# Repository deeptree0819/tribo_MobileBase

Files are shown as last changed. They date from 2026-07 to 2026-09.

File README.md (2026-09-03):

# Tribo MobileBase

Yahboom **Rosmaster STM32 ROS 확장보드** 기반 차동구동(differential drive) 모바일 로봇용 ROS 2 패키지.
새 로봇(Ubuntu 24.04 / ROS 2 Jazzy)에서 처음부터 세팅하는 절차를 정리한 문서입니다.

> 기존 환경은 **ROS 2 Jazzy + Ubuntu 24.04** 기준입니다. 다른 배포판을 쓴다면 아래 `jazzy`를 해당 배포판 이름으로 바꾸세요.

---

## 1. 패키지 구성

| 패키지 | 역할 |
|---|---|
| `tribo_bringup` | HW 인터페이스: `/cmd_vel` → 모터 PWM, 엔코더 퍼블리시 (`tribolib.py` 사용) |
| `tribo_odom` | 엔코더 → `/odom` + TF (`odom`→`base_link`) |
| `tribo_description` | URDF(xacro) 로봇 모델 |
| `tribo_navigation`  | Nav2 / SLAM Toolbox 설정·런치 |
| `tribo_gazebo` | Gazebo 시뮬레이션 |
| `sllidar_ros2` | RPLIDAR 드라이버 (**git 서브모듈**) |
| `hardware` | Tribo mobile base의 설계 파일 |

데이터 흐름: `bringup`(보드 시리얼) → `encoder_raw` → `odom_publisher`(`/odom`+TF) → `nav2`

---

## 2. 사전 요구사항

- Ubuntu 24.04
- [ROS 2 Jazzy](https://docs.ros.org/en/jazzy/Installation.html) 설치 완료
- Yahboom Rosmaster STM32 확장보드 (USB-시리얼 CH340) 연결
- RPLIDAR (C1 등, USB-시리얼 CP2102N) 연결

---

## 3. 원격 접속 (SSH) 설정 — 헤드리스 라즈베리파이

라즈베리파이 기반 로봇은 보통 모니터 없이 PC에서 SSH로 접속해 작업합니다. **새로 설치한 OS는 SSH 서버(sshd)가 없거나 비활성 상태**일 수 있어, 처음 한 번은 직접 켜줘야 합니다.

### 3-1. 증상 진단 (PC에서)

PC에서 접속이 안 될 때, 먼저 원인을 구분합니다.

```bash
ping -c 3 <robot-ip>           # 호스트가 살아있는지
nc -vz <robot-ip> 22           # 22번 포트(sshd) 상태
```

| `nc` 결과 | 의미 | 조치 |
|---|---|---|
| `succeeded` | sshd 정상 | 바로 `ssh` 접속 (3-3) |
| `Connection refused` | 호스트는 살아있으나 **sshd 미기동/미설치** | 3-2로 |
| `timed out` | 방화벽 차단 또는 IP/네트워크 문제 | IP 재확인 / `sudo ufw allow ssh` |

> `ping`은 되는데 `nc ... 22`가 **Connection refused**면 거의 항상 라즈베리파이의 SSH가 꺼져 있는 것입니다(네트워크·IP는 정상).

### 3-2. SSH 서버 설치·활성화 (라즈베리파이 본체에서)

모니터+키보드를 연결하거나 SD카드 콘솔에서 실행합니다.

```bash
# 이미 설치돼 있고 꺼져만 있다면 이 줄만으로 충분
sudo systemctl enable --now ssh

# "Unit ssh.service not found"처럼 sshd 자체가 없다면 설치부터
sudo apt update
sudo apt install -y openssh-server
sudo systemctl enable --now ssh

sudo systemctl status ssh      # active (running) 확인
```

> 헤드리스(모니터 없음)로 처음부터 켜려면: SD카드를 PC에 꽂아 boot 파티션에 **빈 `ssh` 파일**(확장자 없음)을 만들면 부팅 시 자동 활성화됩니다 — `touch /media/$USER/bootfs/ssh` (파티션명은 `ls /media/$USER/`로 확인).

### 3-3. 접속 확인 (PC에서)

```bash
nc -vz <robot-ip> 22           # 이제 succeeded!
ssh <robot-user>@<robot-ip>    # 예: ssh tribo@192.168.210.20
```

> 로봇마다 **계정명이 다를 수 있습니다.** 라즈베리파이에서 `whoami`로 확인하세요. `tribo` 같은 접속 alias를 쓴다면 `type tribo`로 실제 가리키는 대상이 해당 로봇과 맞는지 점검하세요(IP만 바꾸고 옛 계정을 가리키면 인증 단계에서 실패).
>
> 여기까지는 IP로 접속하지만, 키 등록(3-4) 후에는 **3-4-1처럼 호스트명 별칭(`tribo-robot`)으로 고정**하는 것을 권장합니다. 이 문서의 이후 예시는 모두 그 별칭을 씁니다.

### 3-4. SSH 키 등록 (비밀번호 없이 접속)

매번 비밀번호를 입력하지 않도록 PC의 공개키를 로봇에 등록합니다. 자동화 스크립트나 `scp`, 원격 launch에도 필수입니다.

```bash
# PC에 키가 없다면 먼저 생성 (이미 있으면 생략)
ls ~/.ssh/id_ed25519.pub || ssh-keygen -t ed25519

# 공개키를 로봇에 등록 — 이때 한 번만 비밀번호 입력
ssh-copy-id <robot-user>@<robot-ip>      # 예: ssh-copy-id tribo@192.168.210.20

# 확인 — 이제 비밀번호 없이 접속돼야 함
ssh <robot-user>@<robot-ip> 'echo OK'
```

### 3-4-1. 로봇 IP 확인하고 접속하기

**tribo 기체는 모두 같은 이미지로 굽기 때문에 hostname이 전부 `tribo-robot`으로 동일합니다.** 그래서 `tribo-robot.local` 같은 mDNS 이름으로는 **어느 기체인지 특정할 수 없습니다.** 같은 와이파이에 두 대 이상 켜면 이름이 충돌해, 접속이 실패하는 게 아니라 **"먼저 부팅한 아무 기체"에 붙습니다** — 의도한 로봇이 아닐 수 있는데도 성공한 것처럼 보이므로 가장 위험한 실패 방식입니다.

따라서 **접속 대상 로봇에서 직접 IP를 확인한 뒤 그 IP로 붙습니다.**

```bash
# ① 로봇에서 (모니터·키보드 연결 상태) — 자기 IP 확인
hostname -I                    # 가장 간단. 예: 192.168.210.23
ifconfig wlan0 | grep inet     # 또는 이렇게
```

```bash
# ② PC에서 — 확인한 IP로 접속
ssh tribo@192.168.210.23
```

> **IP는 DHCP라 재부팅 때마다 바뀔 수 있습니다.** 접속이 안 되면 ①부터 다시 하세요. 특히 **옛 IP를 다른 기기가 가져간 경우 `timed out`이 아니라 `Connection refused`가 뜹니다** — "로봇이 꺼졌다"고 오진하기 쉬우니, 증상보다 ①의 실제 IP를 믿으세요.

**IP를 여러 곳에 흩뿌리지 마세요.** 확인한 IP는 `~/.ssh/config` **한 곳에만** 적고, 나머지 명령·스크립트·문서는 별칭(`tribo-robot`)만 참조합니다. IP가 바뀌면 이 파일의 `HostName` 한 줄만 고치면 됩니다.

```bash
# PC ~/.ssh/config — IP를 적는 유일한 장소
Host tribo-robot
  HostName 192.168.210.23        # ← ①에서 확인한 IP. 바뀌면 이 줄만 갱신
  User tribo
  IdentityFile ~/.ssh/id_ed25519
  StrictHostKeyChecking accept-new
```

```bash
ssh tribo-robot 'hostname'       # → tribo-robot (접속 확인)
```

#### 지금 붙은 게 정말 그 기체인가 — 시리얼로 확인

hostname이 전부 같으므로 이름으로는 기체를 구별할 수 없습니다. **라즈베리파이 시리얼은 SoC에 박혀 있어 위조·변경이 불가능하므로**, 여러 대를 다룰 때는 이것을 기체 식별의 기준으로 삼으세요.

```bash
ssh tribo-robot 'grep -m1 "^Serial" /proc/cpuinfo'
# Serial : 7b6a4fe0834ff68f    ← 이 기체의 고유 번호
```

기체별 시리얼을 적어두고, 캘리브·배포 전에 대조하면 **엉뚱한 로봇에 밀어 넣는 사고를 막을 수 있습니다.**

| 기체 | Pi 시리얼 | 비고 |
|---|---|---|
| v2 | `7b6a4fe0834ff68f` | Raspberry Pi 5 Model B Rev 1.1 |
| v1 | (미확인) | 켤 때 채워 넣을 것 |
| v3 | (미확인) | 켤 때 채워 넣을 것 |

> **기체를 교체하면** hostname·IP가 같아도 SSH 호스트키가 다르므로 `REMOTE HOST IDENTIFICATION HAS CHANGED` 경고가 뜹니다. 기체를 바꾼 게 맞다면 정상이니 3-5의 절차로 옛 키를 지우고 재접속하세요. **다만 기체를 바꾼 적이 없는데 이 경고가 뜬다면 지우지 말고 의심하세요** — 의도치 않게 다른 로봇에 붙고 있다는 신호입니다.

### 3-4-2. 자주 쓰는 alias 모음 (선택)

작업 편의를 위해 `~/.bashrc`에 아래를 둘 수 있습니다. 실제로 쓰고 있는 구성입니다.

```bash
# PC + 로봇 공통 — 워크스페이스 활성화
alias tribo_ws="source ~/tribo_ws/install/local_setup.bash; echo \"tribo_ws is activated\""

# PC — 로봇 접속 (IP는 ~/.ssh/config 의 tribo-robot 한 곳에서만 관리)
alias tribo="ssh tribo-robot"       # 접속은 이걸로: $ tribo

# PC — 실행 중인 launch 정리 (Ctrl+C로 안 죽은 노드가 남을 때)
alias kbringup='pkill -f "ros2 launch tribo_bringup"'
alias knav='pkill -f "ros2 launch tribo_navigation"'
alias kall='pkill -f "ros2 launch tribo"'      # bringup + navigation 전부
```

수정 후 `source ~/.bashrc` 로 반영합니다.

> **이름이 둘인 이유** — 헷갈리기 쉬우니 정리하면:
> - **`tribo`** = PC에서 **사람이 직접 치는** 접속 alias. 터미널에서 `tribo` 한 단어면 로봇에 붙습니다.
> - **`tribo-robot`** = `~/.ssh/config` 의 **Host 별칭**. bash alias는 대화형 셸에서만 로드되므로 `scp`·스크립트·`ssh <host> '<command>'` 같은 비대화형 호출에는 안 먹습니다. 그런 곳에는 `tribo-robot` 을 쓰세요 (예: `scp map.yaml tribo-robot:~/`).
>
> 즉 **PC에서 접속할 땐 `tribo`, 문서·스크립트에 적을 땐 `tribo-robot`** 입니다. **IP는 `~/.ssh/config` 에만 적고, 이 둘 어디에도 쓰지 않습니다** — 그래야 IP가 바뀌어도 고칠 곳이 한 줄뿐입니다.

### 3-5. 호스트키 변경 경고 — 같은 이름/IP로 다른 로봇에 접속할 때 (PC에서)

**기체를 바꿨거나**(tribo v1 → v2 처럼 hostname이 같은 다른 장비), 기존 로봇과 **같은 IP를 재사용하는 새 로봇**(재설치/보드 교체 포함)에 접속하면, 그 장비는 다른 호스트키를 갖고 있어 PC가 이렇게 막습니다.

```
@@@@@@@@@@@@@@@@@@@@@@@@@@@@@@@@@@@@@@@@@@@@@@@@@@@@@@@@@@@
@    WARNING: REMOTE HOST IDENTIFICATION HAS CHANGED!     @
@@@@@@@@@@@@@@@@@@@@@@@@@@@@@@@@@@@@@@@@@@@@@@@@@@@@@@@@@@@
...
Offending ED25519 key in /home/<user>/.ssh/known_hosts:41
Host key verification failed.
```

이건 MITM 공격이 아니라 **로봇이 바뀌었으니 당연한 경고**입니다(PC의 `known_hosts`에 옛 로봇의 키가 남아 있는 것). 해당 IP의 옛 키만 지우면 됩니다.

```bash
# PC에서 — 옛 호스트키 제거 (백업은 known_hosts.old 로 자동 보관됨)
ssh-keygen -f ~/.ssh/known_hosts -R <robot-ip>      # 예: -R 192.168.210.23

# 다시 접속하면 새 키 등록 여부를 물어봄 → yes
ssh <robot-user>@<robot-ip>
# The authenticity of host ... can't be established.
# Are you sure you want to continue connecting (yes/no/[fingerprint])?  → yes
```

> 접속이 뜨면 로봇에서 `whoami`/`hostname`으로 **계정·호스트명이 맞는 로봇인지** 한 번 확인하세요(옛 로봇과 IP만 같고 실제로 다른 장비일 수 있음). 이후 `ssh-copy-id`(3-4)로 공개키를 다시 등록하면 비밀번호 없이 접속됩니다.

---

## 4. 설치

> **📍 대상: PC와 로봇 양쪽에서 각각 수행합니다.** 두 머신 모두 자기 `~/tribo_ws`를 갖고 빌드합니다 — 로봇은 실제 bringup·주행용, PC는 시뮬레이션·RViz·개발용. (하드웨어 설정인 5장만 **로봇 전용**입니다.)
>
> | 소절 | PC | 로봇 | 비고 |
> |------|:--:|:----:|------|
> | 4-1 시스템 의존성 | ✅ | ✅ | `python3-serial`은 실제로는 로봇에서만 쓰이나, 설치해 둬도 무해 |
> | 4-2 ROS 2 패키지 의존성 | ✅ | ✅ | 시뮬(gazebo) 블록은 **PC만** |
> | 4-3 워크스페이스 clone | ✅ | ✅ | 각 머신에 독립적으로 clone |
> | 4-4 빌드 | ✅ | ✅ | 각 머신에서 `colcon build` |

### 4-1. 시스템 의존성 &nbsp;·&nbsp; 🖥️ PC + 🤖 로봇

```bash
sudo apt update
sudo apt install -y \
  python3-serial \
  python3-colcon-common-extensions \
  git
```

> `python3-serial`(pyserial)은 `tribolib.py`가 보드와 통신하는 데 **유일하게 필요한 외부 파이썬 의존성**입니다. (Yahboom의 `Rosmaster_Lib`는 따로 설치할 필요 없음 — `tribolib.py`가 프로토콜을 자체 구현)
>
> `python3-colcon-common-extensions`가 `Unable to locate package`로 안 잡히면 **ROS 2 apt 저장소가 아직 추가되지 않은 것**입니다(이 패키지는 packages.ros.org에 있음). 2장의 ROS 2 Jazzy 설치를 먼저 끝내면 잡힙니다.

### 4-2. ROS 2 패키지 의존성 &nbsp;·&nbsp; 🖥️ PC + 🤖 로봇

```bash
sudo apt install -y \
  ros-jazzy-geometry-msgs \
  ros-jazzy-sensor-msgs \
  ros-jazzy-std-msgs \
  ros-jazzy-nav-msgs \
  ros-jazzy-tf2-ros \
  ros-jazzy-xacro \
  ros-jazzy-joint-state-publisher \
  ros-jazzy-joint-state-publisher-gui \
  ros-jazzy-robot-state-publisher \
  ros-jazzy-rviz2 \
  ros-jazzy-nav2-bringup \
  ros-jazzy-slam-toolbox \
  ros-jazzy-laser-filters
```

> `laser_filters`는 라이다 자기 몸체(기둥·버튼 등) 반사를 걸러 `/scan` → `/scan_filtered`를 만듭니다. **필수입니다.** 빠지면 map_building이 `package 'laser_filters' not found`로 즉시 죽습니다.
>
> ⚠️ `use_scan_filter:=false`는 **우회 수단이 아닙니다.** 필터 노드만 안 띄울 뿐, SLAM·AMCL·nav2 코스트맵은 전부 `/scan_filtered`를 구독하도록 설정돼 있어(`nav2_params.yaml`, `slam_toolbox_mapping.yaml`, `nav2_localization.yaml`) 아무도 발행하지 않는 토픽을 기다리며 스캔을 한 개도 못 받습니다. 런치는 뜨지만 맵이 안 그려집니다.

시뮬레이션(`tribo_gazebo`)도 쓸 경우 &nbsp;·&nbsp; **🖥️ PC 전용** (로봇에선 불필요):

```bash
sudo apt install -y \
  ros-jazzy-ros-gz-sim \
  ros-jazzy-ros-gz-bridge \
  ros-jazzy-ros-gz-image
```

### 4-3. 워크스페이스 클론 (서브모듈 포함) &nbsp;·&nbsp; 🖥️ PC + 🤖 로봇 (각각)

`sllidar_ros2`는 서브모듈이므로 `--recurse-submodules`가 필수입니다.

```bash
mkdir -p ~/tribo_ws/src
cd ~/tribo_ws/src
git clone --recurse-submodules https://github.com/deeptree0819/tribo_MobileBase.git tribo

# 이미 서브모듈 없이 클론했다면:
cd ~/tribo_ws/src/tribo
git submodule update --init --recursive
```

### 4-4. 빌드 &nbsp;·&nbsp; 🖥️ PC + 🤖 로봇 (각각)

```bash
cd ~/tribo_ws
source /opt/ros/jazzy/setup.bash
colcon build --symlink-install
source install/setup.bash
```

---

## 5. 하드웨어 설정 &nbsp;·&nbsp; 🤖 로봇 전용

### 5-1. 시리얼 포트 접근 권한

`dialout` 그룹에 사용자를 추가해야 보드/라이다 시리얼 포트(`/dev/ttyUSB*`)에 접근할 수 있습니다. 추가하지 않으면 bringup이 `could not open port` 로 실패합니다.

```bash
# 로봇에서 (SSH로 접속한 상태). sudo 비밀번호를 한 번 입력
sudo usermod -aG dialout $USER

# 그룹 변경은 새 로그인 세션부터 적용 → 재로그인(또는 재부팅) 필수
exit
ssh <robot-user>@<robot-ip>     # 다시 접속
# 또는: sudo reboot

# 확인 — 목록에 dialout 이 보이면 성공
groups
# tribo adm dialout cdrom sudo ...
```

> `/dev/ttyUSB0` 권한은 `crw-rw---- root dialout`이라, dialout 그룹에 들기 전에는 같은 사용자라도 포트를 열 수 없습니다.

CH340 / CP2102 드라이버는 최신 커널에 기본 내장돼 있어 보통 별도 설치가 필요 없습니다.
연결 확인:

```bash
ls -l /dev/serial/by-id/
# 예시:
#   usb-1a86_USB_Serial-if00-port0                → 보드(ttyUSB0)
#   usb-Silicon_Labs_CP2102N_..._if00-port0       → 라이다(ttyUSB1)
```

### 5-2. USB 장치 고정 이름 (udev) — 권장

USB 포트를 다른 소켓에 꽂거나 부팅 순서가 바뀌면 `/dev/ttyUSB0`↔`ttyUSB1`이 뒤바뀌어 **보드와 라이다가 서로 포트를 뺏는** 문제(보드 `multiple access on port`, 라이다 `OPERATION_TIMEOUT`)가 생길 수 있습니다. udev 규칙으로 칩 종류(VID:PID) 기반 고정 심볼릭을 만들어 원천 차단합니다.

repo에 규칙 파일이 포함돼 있습니다: `tribo_bringup/udev/99-tribo-serial.rules`

```bash
# 로봇에서 (sudo 비밀번호 1회)
sudo cp ~/tribo_ws/src/tribo/tribo_bringup/udev/99-tribo-serial.rules /etc/udev/rules.d/
sudo udevadm control --reload-rules && sudo udevadm trigger

# 확인 — 두 심볼릭이 보이면 성공
ls -l /dev/tribo_base /dev/tribo_lidar
#  /dev/tribo_base  -> ../../ttyUSB0
#  /dev/tribo_lidar -> ../../ttyUSB1
```

| 장치 | 매칭 기준 | 고정 이름 |
|---|---|---|
| 보드 (CH340) | VID:PID `1a86:7523` | `/dev/tribo_base`  |
| 라이다 (CP2102N) | VID:PID `10c4:ea60` | `/dev/tribo_lidar` |

> - 보드/라이다 칩이 위와 다르면 규칙 파일의 VID:PID를 자기 장치 값(`udevadm info -q property -n /dev/ttyUSB0`의 `ID_VENDOR_ID`/`ID_MODEL_ID`)으로 바꾸세요.
> - 같은 칩(예: CP2102N 2개)을 동시에 꽂는 경우에만 VID:PID로 구분이 안 됩니다. 그땐 규칙 파일 주석대로 라이다 줄에 `ATTRS{serial}=="<고유시리얼>"`을 추가하세요.

### 5-3. 보드·라이다 포트 해석 (자동)

`bringup.launch.py`가 시작할 때 포트를 **자동 해석**합니다 — udev 심볼릭(`/dev/tribo_base`, `/dev/tribo_lidar`)이 있으면 그것을, 없으면 `/dev/serial/by-id/` 경로로 폴백합니다. 따라서 **5-2의 udev 설치를 건너뛰어도** by-id로 동작하고, ttyUSB 번호 변동에는 항상 안전합니다.

- **보드**: `bringup.yaml`에는 `port`를 두지 않고 launch가 해석한 값을 사용합니다.
- **라이다**: `bringup.launch.py`가 해석한 `serial_port`를 sllidar 런치에 넘깁니다 — `sllidar_c1_launch.py`를 직접 고칠 필요가 없습니다.

> 칩이 다른 보드/라이다를 쓰면 `bringup.launch.py` 상단의 `_resolve_port(...)` 매칭 문자열과 `udev/99-tribo-serial.rules`의 VID:PID를 함께 바꾸세요.

### 5-4. CPU 거버너 = performance ⚠️ (Pi5 + Nav2 필수)

라즈베리파이 기본 CPU 거버너는 `ondemand`라 부하에 따라 클럭을 **천천히** 올립니다. Nav2 12개 노드가 한꺼번에 뜨는 **버스트 시작** 때 클럭(2.4GHz)이 못 따라와서:

- `controller_server`가 costmap 로딩에 너무 오래 걸려 → `lifecycle_manager: get_state service is not available! Aborting bringup` 으로 **nav 전체가 abort**

거버너를 `performance`(전 코어 최대 클럭 고정)로 바꾸면 해결됩니다.

```bash
# 즉시 적용 (재부팅 전까지)
echo performance | sudo tee /sys/devices/system/cpu/cpu*/cpufreq/scaling_governor

# 확인 — performance / 2400000(2.4GHz) 나와야 함
cat /sys/devices/system/cpu/cpu0/cpufreq/scaling_governor
cat /sys/devices/system/cpu/cpu*/cpufreq/scaling_cur_freq
```

재부팅해도 유지하려면 repo의 systemd 서비스를 설치:

```bash
sudo cp ~/tribo_ws/src/tribo/tribo_bringup/system/cpu-performance.service /etc/systemd/system/
sudo systemctl daemon-reload
sudo systemctl enable --now cpu-performance.service
systemctl is-enabled cpu-performance.service                 # enabled 면 OK
systemctl is-active  cpu-performance.service                 # active 면 OK

# 재부팅 후 검증 — 4코어 전부 performance 나와야 함
cat /sys/devices/system/cpu/cpu*/cpufreq/scaling_governor
```

> performance 거버너는 발열·소비전력이 늘어납니다. Pi5는 액티브 쿨러가 있으면 문제없습니다. Nav2를 안 쓰고 bringup만 돌릴 땐 `ondemand`로도 충분합니다.

### 5-5. 뎁스 카메라 (Intel RealSense D435)

#### 5-5-1. USB 3.0 포트에 연결 ⚠️

**가장 흔한 실패 지점입니다.** D435는 depth와 color 영상을 동시에 보내므로 USB 3.0이 필요합니다. USB 2.0에 물리면 동작은 하지만 **프레임레이트가 절반**으로 떨어집니다.

| 연결 | depth | color |
|---|---|---|
| USB 2.0 | 640×480 @ **15 fps** | 640×480 @ **15 fps** |
| USB 3.0 | 848×480 @ **30 fps** | 640×480 @ **30 fps** |

대역폭을 계산하면 이유가 보입니다. depth 640×480×16bit @30fps ≈ 147 Mbps, color도 비슷해서 합치면 약 300 Mbps인데 USB 2.0의 실효 대역폭이 그 언저리입니다. 그래서 librealsense가 두 스트림을 다 내보내려고 **알아서 15fps로 낮춥니다** — 에러가 아니라 조용한 성능 저하라 놓치기 쉽습니다.

- **소켓**: Pi5의 **파란색** USB-A (검은색은 USB 2.0). Pi5의 USB-C는 **전원 전용**이라 데이터가 안 됩니다.
- **케이블**: **USB 3.0 이상, A to C**. USB-A 단자 안쪽이 파란색이고 핀이 9개면 3.0, 흰색이고 4개면 2.0입니다. "고속충전"만 적힌 케이블은 데이터가 2.0인 경우가 흔합니다.

연결 후 협상 속도를 확인합니다. **`5000`이 나와야 정상**이고 `480`이면 USB 2.0입니다.

```bash
for d in /sys/bus/usb/devices/*/; do [ -f "$d/idVendor" ] && [ "$(cat $d/idVendor)" = "8086" ] && cat "$d/speed"; done
```

`480`이 나오면 어느 소켓이 3.0인지 실측으로 찾습니다. 아래를 띄워둔 채 카메라를 뽑았다 꽂으면 소켓마다 한 줄씩 나옵니다 — `SuperSpeed`가 USB 3.0, `high-speed`가 USB 2.0입니다.

```bash
sudo dmesg -w | grep --line-buffered "new .*USB device"
```

> **라이다와 보드는 검은 소켓으로 충분합니다.** 둘 다 USB 시리얼 변환기라 12 Mbps 수준으로 동작합니다. 파란 소켓에 꽂아도 보드레이트(115200~256000 bps)가 상한이라 아무 이득이 없습니다. 파란 소켓 2개는 카메라 몫으로 남겨두세요.

#### 5-5-2. 패키지 설치

ROS 저장소에 arm64 바이너리가 있어 **소스 빌드가 필요 없습니다**.

```bash
sudo apt update
sudo apt install -y ros-jazzy-realsense2-camera ros-jazzy-realsense2-description
```

`ros-jazzy-librealsense2`는 의존성으로 함께 설치됩니다.

> **⚠️ 노드가 `undefined symbol`로 죽으면 `diagnostic_updater`를 올리세요.**
> ROS 패키지를 오래 업데이트하지 않은 기체에서 나타납니다.
>
> ```
> [realsense2_camera_node-1] terminate called after throwing an instance of 'class_loader::LibraryLoadException'
>   what():  Could not load library ... librealsense2_camera.so: undefined symbol: _ZN18diagnostic_updater7Updater...
> ```
>
> 새로 받은 `realsense2_camera`가 빌드된 버전과 기체에 깔린 `diagnostic_updater`의 ABI가 안 맞아서입니다. 해결:
>
> ```bash
> sudo apt install -y --only-upgrade ros-jazzy-diagnostic-updater ros-jazzy-diagnostic-msgs
> ```
>
> (기체 7b6a에서 4.2.6 → 4.2.7 업그레이드로 해결. 같은 날 76c02a는 이미 4.2.7이라 문제가 없었습니다.)

#### 5-5-3. 접근 권한

```bash
sudo usermod -aG video $USER
```

그룹 변경은 **재로그인(또는 재부팅) 후 적용**됩니다.

> **이 단계를 건너뛰면 "될 때도 있고 안 될 때도 있는" 상태가 됩니다.** `/dev/video*`는 `uaccess` 태그가 붙어 있어, 로봇 화면에 사용자가 로그인해 있으면 systemd-logind가 그 세션에 ACL을 임시로 부여합니다. 그래서 LCD에 로그인된 상태에서는 `video` 그룹 없이도 카메라가 열립니다. 하지만 자동 로그인을 끄거나 콘솔 세션이 없으면 SSH로만 접속했을 때 권한 오류가 납니다. `video` 그룹에 넣어두면 세션 상태와 무관하게 항상 열립니다.

#### 5-5-4. 실행

```bash
ros2 launch realsense2_camera rs_launch.py
```

포인트클라우드(`/camera/camera/depth/color/points`)는 기본으로 꺼져 있습니다. 3D로 보려면:

```bash
ros2 launch realsense2_camera rs_launch.py pointcloud.enable:=true
```

#### 5-5-5. 동작 확인

```bash
ros2 topic list | grep camera
ros2 topic hz /camera/camera/depth/image_rect_raw
```

USB 3.0이면 **30 Hz**, USB 2.0이면 15 Hz가 나옵니다. 노드 로그에도 `Device USB type: 3.2`처럼 찍히고, USB 2.0이면 `Reduced performance is expected` 경고가 함께 나옵니다.

| 증상 | 원인 |
|---|---|
| 토픽이 아예 안 보임 | `ROS_DOMAIN_ID` 불일치 (6장 참고) |
| 15 fps에서 안 올라감 | USB 2.0 연결 — 5-5-1 |
| 권한 오류로 열리지 않음 | `video` 그룹 미반영 — 재로그인 필요 |
| 모터가 안 먹음 | 카메라 꽂다가 보드(CH340) USB를 뽑았는지 확인 |

#### 5-5-6. 로봇 LCD에 영상 띄우기

PC 없이 로봇 화면만으로 카메라 영상을 확인할 수 있습니다. 실습·시연에 유용합니다.

**전제 조건 두 가지**가 있습니다.

1. **LCD에 GNOME 세션이 로그인돼 있어야 합니다.** 자동 로그인이 켜져 있으면 부팅만으로 충족됩니다.

```bash
grep AutomaticLogin /etc/gdm3/custom.conf
```

2. **화면이 꺼지지 않아야 합니다.** Ubuntu Desktop 기본값은 5분 뒤 화면을 끄고(`idle-delay=300`), 나아가 **기체 전체를 서스펜드**합니다(`sleep-inactive-ac-type='suspend'`). 로봇에는 둘 다 위험하므로 시스템 기본값으로 꺼둡니다.

```bash
sudo tee /etc/dconf/profile/user <<'EOF'
user-db:user
system-db:local
EOF
sudo mkdir -p /etc/dconf/db/local.d
sudo tee /etc/dconf/db/local.d/00-tribo-lcd <<'EOF'
[org/gnome/desktop/session]
idle-delay=uint32 0

[org/gnome/desktop/screensaver]
lock-enabled=false
idle-activation-enabled=false

[org/gnome/settings-daemon/plugins/power]
idle-dim=false
sleep-inactive-ac-type='nothing'
sleep-inactive-battery-type='nothing'
EOF
sudo dconf update
```

> 사용자 계정 설정(`gsettings set`)이 아니라 **시스템 기본값**으로 두는 이유는, 계정을 새로 만들거나 SD 이미지를 복제해도 그대로 유지되어야 하기 때문입니다. 계정에 개별 설정이 이미 남아 있으면 시스템 기본값이 가려지므로 `dconf reset <키>`로 지워야 합니다.

**띄우기.** 전용 스크립트가 환경변수 조립·전체화면 강제까지 처리합니다.

```bash
sudo apt install -y wmctrl
~/tribo_ws/src/tribo/tribo_bringup/scripts/launch_camera_on_lcd.sh
```

다른 토픽을 보려면 인자로 넘깁니다.

```bash
~/tribo_ws/src/tribo/tribo_bringup/scripts/launch_camera_on_lcd.sh /camera/camera/depth/image_rect_raw
```

`wmctrl`이 없으면 경고를 찍고 창이 작게 뜹니다.

> **depth 를 보려면 `enable_depth:=false` 로 띄우면 안 됩니다.** 그 상태에서도 토픽 이름은 광고되지만 데이터가 흐르지 않아 화면이 검게만 보입니다.
>
> depth 는 컬러 영상이 아니라 **16비트 거리값(`16UC1`, 단위 mm)** 이라 그대로는 표시할 수 없습니다(`[16UC1] is not a color format` 오류). 뷰어가 인코딩을 감지해 자동으로 컬러맵을 입힙니다.
>
> - **파랑 = 가까움, 빨강 = 멀음** (표시 범위 0.3~4.0 m, 스크립트 상단 `DEPTH_MIN_M`/`DEPTH_MAX_M`)
> - **검정 = 측정 실패** — 유리·거울·검은 물체·너무 가까운 면에서 나옵니다. 0 을 그대로 칠하면 "코앞에 물체가 있음"으로 보이므로 일부러 검게 남깁니다
>
> 매 프레임 최소/최대로 정규화하지 않고 **고정 범위**를 쓰는 이유는, 장면이 바뀔 때마다 같은 거리가 다른 색으로 보이면 실습에 쓸 수 없기 때문입니다.

**끄기.** LCD 앞이라면 `q` 또는 `ESC`. SSH라면:

```bash
pkill -f "lcd_camera_view[.]py"
```

카메라 노드까지 내리려면:

```bash
pkill -f realsense2_camera_node
```

> 대괄호(`[.]`)는 오타가 아닙니다. `pkill -f`는 **자기 자신의 명령줄도 검사**하므로, 패턴이 그대로 들어 있으면 스스로를 죽여 뒤 명령이 실행되지 않습니다. `[.]`는 정규식으로는 `.`과 같지만 문자열로는 다르므로 자기 매칭을 피합니다.

**화면이 꺼져 있을 때 깨우기.** 절전 설정을 끄기 **전에** 이미 꺼졌다면 설정만으로는 켜지지 않습니다.

```bash
export DBUS_SESSION_BUS_ADDRESS=unix:path=/run/user/1000/bus
busctl --user call org.gnome.ScreenSaver /org/gnome/ScreenSaver org.gnome.ScreenSaver SetActive b false
```

> 반대로 화면을 **끄는** 것은 같은 호출에 `b true`를 주면 될 것으로 보이지만, 아직 실기에서 확인하지 못했습니다. 확인되면 이 문단을 갱신하세요.

**왜 전용 스크립트인가.** `rqt_image_view`는 창 장식과 툴바가 1024×600 화면의 상당 부분을 먹는데, mutter가 SSH에서 온 리사이즈 요청을 무시해서 크기를 맞출 수도 없습니다(228×169로 뜨는 것을 실측). `lcd_camera_view.py`는 OpenCV 전체화면 창에 영상만 그리고, 화면과 영상의 비율이 달라도 찌그러뜨리지 않고 **비율 유지 확대 후 중앙 크롭**으로 채웁니다.

구현하며 밟은 함정이 스크립트 주석에 남아 있습니다.

| 함정 | 내용 |
|---|---|
| `cv2.getWindowImageRect()` | 창 크기가 아니라 "마지막에 그린 이미지 영역"을 반환. 그 값으로 다시 크기를 정하면 프레임마다 이미지가 줄어듦 |
| `fb0/virtual_size` | 프레임버퍼 콘솔 크기이지 X 모드가 아님. 기체 7b6a에서 fb0는 1024×768, 실제 X는 1024×600. `xrandr`을 써야 함 |
| OpenCV 전체화면 속성 | GNOME Wayland에서 무시됨. `xdotool windowsize`도 무시. `wmctrl -b add,fullscreen`만 먹음 |
| `set -u` + ROS 소싱 | `AMENT_TRACE_SETUP_FILES: unbound variable`로 죽음. 소싱 구간만 `set +u` |

**RViz로 보고 싶다면** (depth·포인트클라우드까지):

```bash
export DISPLAY=:0
export XAUTHORITY=$(ls -t /run/user/$(id -u)/.mutter-Xwaylandauth.* | head -1)
rviz2 --fullscreen
```

좌하단 **Add**로 `Image` 또는 `PointCloud2`를 추가합니다. 포인트클라우드는 카메라를 `pointcloud.enable:=true`로 띄워야 나옵니다.

> Nav2 단계에서는 `bringup_launch.xml`이 `launch_rviz_on_lcd.sh`로 RViz를 자동 표시합니다(7장).

| 증상 | 원인 |
|---|---|
| `cannot open display :0` | LCD에 로그인된 GNOME 세션 없음 — 자동 로그인 확인 |
| `Authorization required` | `XAUTHORITY` 경로가 낡음 — 글롭으로 다시 잡을 것 |
| 창은 떴는데 영상이 검음 | 카메라 노드 미실행 또는 토픽 이름 오타 |
| 창이 작게 뜸 | `wmctrl` 미설치 |
| 화면이 5분 뒤 꺼짐 | 위 dconf 설정 누락 |
| 설정했는데도 화면이 꺼져 있음 | 설정 전에 이미 꺼진 것 — 위 깨우기 명령 실행 |

#### 5-5-7. PC에서 영상 보기

**압축 토픽을 써야 합니다.** 원본을 그대로 구독하면 WiFi가 포화되어 영상뿐 아니라 **Nav2의 costmap·TF 통신까지 밀립니다.**

로봇에 압축 전송 플러그인을 설치하면 `/compressed` 토픽이 생깁니다.

```bash
sudo apt install -y ros-jazzy-compressed-image-transport
```

PC에서:

```bash
export ROS_DOMAIN_ID=38
ros2 run rqt_image_view rqt_image_view /camera/camera/color/image_raw/compressed
```

실측한 대역폭입니다(컬러 1280×720@30, USB 3.0).

| | 메시지 크기 | 30fps 환산 |
|---|---|---|
| 원본 `image_raw` | 2.76 MB | **662 Mbps** |
| 압축 `compressed` | 0.23 MB | **56 Mbps** |

> **압축해도 1280×720@30은 캠퍼스 WiFi에서 버겁습니다.** 실측에서 패킷 손실 33%, RTT 400ms까지 올라가 SSH도 느려졌습니다. Nav2와 함께 쓸 거면 해상도를 낮추세요.
>
> ```bash
> ros2 launch realsense2_camera rs_launch.py enable_depth:=false rgb_camera.profile:=640x480x15
> ```

> **`ROS_DOMAIN_ID`가 다르면 토픽이 아예 안 보입니다.** 기체마다 값이 다릅니다(7b6a=38, 76c02a=21). PC도 같은 값으로 맞추세요.
>
> 로봇 `~/.bashrc`에 넣을 때는 **"비대화형이면 return" 구문보다 위에** 둬야 합니다. 아래에 두면 대화형 셸에서만 잡혀서, `ssh <host> '<명령>'` 형태의 원격 실행에서는 도메인이 0이 되고 "노드가 안 보인다"로 헤매게 됩니다.

---

## 6. ROS_DOMAIN_ID 설정 (PC ↔ 로봇 통신)

PC와 로봇이 서로의 토픽을 보려면 **같은 `ROS_DOMAIN_ID`** 를 써야 합니다. `~/.bashrc` 끝에 추가:

```bash
export ROS_DOMAIN_ID=20          # PC·로봇 동일 값으로
source /opt/ros/jazzy/setup.bash
source ~/tribo_ws/install/setup.bash
```

> alias만 정의해 두고 매번 수동 실행하면 노드별로 도메인이 어긋날 수 있으니, 위처럼 **export로 고정**하는 것을 권장합니다.

---

## 7. 실행

### 7-1. 실제 로봇 bringup (보드 + 오도메트리 + 라이다)

```bash
ros2 launch tribo_bringup bringup.launch.py
```

주요 런치 인자(기본값): `use_odom:=true`, `use_lidar:=true`, `use_description:=true`

모터 구동만 (라이다·odom 제외):

```bash
ros2 launch tribo_bringup bringup.launch.py use_lidar:=false use_odom:=false
```

bringup + odom만 묶은 코어 런치:

```bash
ros2 launch tribo_bringup core.launch.py
```

### 7-2. 동작 테스트

```bash
# 전진 명령 (안전을 위해 바퀴를 들고 테스트 권장)
ros2 topic pub --once /cmd_vel geometry_msgs/Twist "{linear: {x: 0.1}}"
```

> bringup에는 **watchdog**이 있어 `cmd_vel`이 `cmd_timeout`(기본 0.5초)초 동안 끊기면 모터를 자동 정지합니다.

### 7-3. 맵 만들기 (SLAM)

SLAM Toolbox로 지도를 작성합니다. (`ros-jazzy-slam-toolbox` 패키지 필요 — 4-2의 의존성 목록에 포함)

**① 로봇에서: bringup 실행** (모터·오도메트리·라이다·URDF 전체)

```bash
# 로봇 (ssh tribo-robot)
ros2 launch tribo_bringup bringup.launch.py
```

**② SLAM 실행** (로봇 또는 PC, 어느 쪽이든 OK — 같은 `ROS_DOMAIN_ID`만 맞으면 됨)

```bash
ros2 launch tribo_navigation map_building.launch.py
```

이 런치는 내부적으로 다음을 띄웁니다:
- `laser_filters/scan_to_scan_filter_chain` (`/scan` → `/scan_filtered`)
- `slam_toolbox` online sync (`config/slam_toolbox_mapping.yaml`)

**③ 맵이 그려지는 과정 보기**

**로봇 LCD에는 자동으로 뜹니다.** `map_building.launch.py`가 전용 맵 뷰어를 함께 띄웁니다. 맵이 자라면 **배율이 매 프레임 자동으로 맞춰지므로** 실행 중 손댈 것이 없습니다.

| 색 | 의미 |
|---|---|
| 흰색 | 빈 공간 |
| 검정 | 장애물 |
| 회색 | 미탐색 |
| 빨강 점 | 로봇 현재 위치 |

좌하단에 현재 표시 범위가 미터로 찍힙니다. 맵이 커지면 이 숫자가 커집니다.

```bash
# 끄려면
ros2 launch tribo_navigation map_building.launch.py use_lcd_map:=false

# 맵 뷰어 대신 RViz 를 LCD 에 띄우려면 (라이다 스캔·TF 까지 보고 싶을 때)
ros2 launch tribo_navigation map_building.launch.py use_rviz:=true use_lcd_map:=false
```

> RViz 를 쓰지 않는 이유: RViz 의 배율은 설정 파일에 박힌 고정값이라 실행 중 바꾸려면 마우스 휠이 필요한데, 로봇에는 마우스도 키보드도 없습니다. 맵은 매핑 중 계속 자라므로 고정 배율로는 곧 화면을 벗어납니다. 둘을 동시에 켜면 같은 화면을 두고 다투니 하나만 쓰세요.

**PC에서도 보려면** 뷰어를 따로 실행합니다.

```bash
# PC — /map, /scan, 로봇 모델을 map_building.rviz 설정으로 표시
ros2 launch tribo_navigation map_view.launch.py
```

- 실시간으로 채워지는 맵을 보며 아직 안 그려진 곳을 향해 로봇을 몰면 됩니다.
- 시뮬(Gazebo)이면 `use_sim_time:=true`를 붙이세요(안 그러면 TF 시간 불일치로 화면이 비거나 깨짐).
- 순수 뷰어라 로봇 노드는 하나도 안 띄웁니다. 끄거나 재시작해도 SLAM에 영향 없습니다.

**④ 텔레옵으로 주행하며 매핑**

```bash
# 별도 터미널에서 (PC 권장)
ros2 run teleop_twist_keyboard teleop_twist_keyboard
```

> 너무 빠르거나 급회전하면 스캔 매칭이 깨집니다. 천천히, 겹치는 구간을 만들면서 한 바퀴 돌리세요.

**⑤ 맵 저장**

`map_saver_cli`는 **실행한 머신의 현재 경로**에 `<이름>.yaml` + `<이름>.pgm` 두 파일을 저장합니다. Nav2가 결국 **로봇에서** map을 로드하므로, 가능하면 **로봇에서 저장**하는 게 가장 간단합니다.

```bash
# 로봇에서 저장 → /home/tribo/my_map.{yaml,pgm} 생성됨
ros2 run nav2_map_server map_saver_cli -f ~/my_map
```

PC에서 저장한 경우, 로봇으로 복사해야 합니다:

```bash
# PC에서 저장했다면
ros2 run nav2_map_server map_saver_cli -f ~/my_map
scp ~/my_map.yaml ~/my_map.pgm tribo-robot:~/
```

> **최종 상태**: 로봇 측 홈(`~`, 예: `/home/tribo/`)에 `my_map.yaml` + `my_map.pgm` 두 파일이 있어야 다음 단계(Navigation)가 동작합니다.

### 7-4. Navigation 실행 (Nav2)

저장한 맵 위에서 AMCL 자기위치추정 + Nav2 플래너/컨트롤러로 자율 주행합니다.

**① 로봇에서: bringup 실행**

```bash
# 로봇
ros2 launch tribo_bringup bringup.launch.py
```

**② 로봇에서: Nav2 전체 스택 실행** (localization + navigation 합본)

```bash
# 로봇 — map 경로는 "로봇 입장의 절대경로"여야 함
ros2 launch tribo_navigation bringup_launch.xml \
  map:=/home/tribo/my_map.yaml \
  set_initial_pose:=false
```

- `set_initial_pose:=false`로 띄우면 초기 위치를 자동으로 발행하지 않으므로, 다음 단계에서 RViz "2D Pose Estimate"로 직접 찍어줘야 `map`→`odom` TF가 살아납니다.
- 처음부터 원점에서 시작한다는 게 확실하면 `set_initial_pose:=true`(기본값) + `initial_pose_x/y/yaw`로 자동 발행도 가능합니다.
- 위 launch는 **로봇에 연결된 LCD에 RViz2를 전체화면으로 자동 표시**합니다(`use_rviz:=true` 기본). RViz가 필요 없으면 `use_rviz:=false`로 끄세요. LCD 표시는 GNOME 데스크톱 세션의 Xwayland(`:0`)에 X 앱을 띄우는 방식이라, **로봇 LCD에 사용자가 한 번 로그인되어 GNOME 세션이 살아있어야** RViz 창이 화면에 뜹니다(자동 로그인이 꺼져 있다면 부팅 후 LCD에서 한 번 로그인 필요).
- **화면 배율은 맵 크기에 맞춰 자동 조정됩니다.** launch 가 `map` 을 wrapper 에 넘기면 `fit_rviz_to_map.py` 가 맵 yaml 의 해상도와 PGM 픽셀 크기로 실제 범위를 구해 `Scale`·중심을 다시 계산합니다. 맵을 새로 만들어도 손댈 것이 없습니다.

  > `navigation.rviz` 의 고정 배율(89.86)을 그대로 쓰면 맵 일부만 화면에 들어옵니다. 실측에서 20.4×14.65 m 맵에 대해 `Scale` 이 25.13 로 조정됐습니다. 맞춤 생성이 실패해도 원본 설정으로 그냥 뜨므로 Nav2 기동을 막지는 않습니다.

**③ (선택) PC에서도 RViz 따로 보기**

LCD 화면이 작거나 별도 모니터로 보고 싶을 때만. 같은 토픽을 PC의 큰 화면에서 동시에 볼 수 있습니다(로봇 LCD의 RViz와 무관).

```bash
# PC
ros2 launch tribo_navigation nav2_view.launch.xml
```

**④ RViz 조작**
1. 상단 툴바 **"2D Pose Estimate"** 클릭 → 맵 상의 실제 로봇 위치/방향을 클릭+드래그로 지정 (한 번만 하면 됨)
2. 상단 툴바 **"Nav2 Goal"** 클릭 → 목표 위치 클릭+드래그 → 자동 주행 시작

**⑤ 동작 검증**

```bash
# 로봇에서 (또는 PC에서, 도메인만 같으면 됨)
ros2 lifecycle get /map_server     # → active [3]
ros2 lifecycle get /amcl           # → active [3]
ros2 run tf2_ros tf2_echo map odom # → 주기적으로 transform 출력되면 OK
ros2 topic echo /amcl_pose --once  # 현재 추정 위치
```

> **⚠️ 함정 — Nav2 단독 런치만 띄우면 안 됨**
>
> `tribo_navigation/launch/navigation_launch.xml`은 컨트롤러/플래너/BT/스무더 등 **주행 관련 노드만** 띄우는 부분 런치입니다. 단독 실행하면 `map_server`·`amcl`이 안 떠서 `map` 프레임이 생기지 않고, `tf2_echo map odom`이 영원히 대기합니다. **반드시 `bringup_launch.xml`(= localization + navigation 합본)을 사용하세요.**
>
> **⚠️ 함정 — `map:=` 경로는 launch가 실행되는 머신 기준**
>
> 위 예시는 로봇에서 `ros2 launch`를 실행하므로 `map:=/home/tribo/my_map.yaml`(로봇 홈) 입니다. 만약 PC에서 launch를 실행한다면 PC 입장 경로(`/home/deeptree/...`)로 줘야 합니다. PC의 `/home/deeptree/...`를 로봇 launch에 넘기면 `map_server` configure가 "파일을 못 찾는다"며 실패합니다.

### 7-5. 시뮬레이션 (Gazebo) — SLAM/Nav 실습

실로봇 없이 PC에서 SLAM·Nav2를 실습할 수 있도록 Gazebo(gz-sim) 환경을 제공합니다.

**구성**
- **로봇 모델**: 2단 트롤리 외형(하단 구동 베이스 + 모터 4 + 상단 프로파일 프레임 + 선반 플레이트 + LCD). 4륜 차동구동(skid-steer).
- **센서**: 2D 라이다(`/scan`), Depth 카메라(`/camera/image`, `/camera/depth_image`, `/camera/points`, `/camera/camera_info`)
- **월드** (`tribo_gazebo/worlds/tribo_world.world`): 16×12 m 실내 — 방 3개 + 복도 + 문 3개 + 장애물 9개(루프 클로저·장애물 회피 연습용). 외부 모델 의존성 없는 self-contained. 복도·문 폭은 2.0 m — 로봇 전폭이 0.78 m 라 예전 1.0 m 로는 Nav2 가 경로를 못 냈다.
- **odom 보정 완료**: 4륜 스키드 회전 슬립 때문에 `gazebo_control.xacro`의 `wheel_separation`을 물리 트랙(0.74)이 아닌 **유효 트랙 0.95**로 설정(2026-08-21 재측정). 직진은 오차 0%, 회전은 254° 당 약 3.5° 남는다.

**① 시뮬 실행**

```bash
ros2 launch tribo_gazebo launch_sim.launch.xml
```
→ 실내 맵 + 로봇(복도 서쪽 `-3, 0`)이 스폰됩니다. (빈 월드는 `launch_sim_empty.launch.xml`)

**② SLAM 맵 작성** (새 터미널)

```bash
ros2 launch tribo_navigation map_building.launch.py use_sim_time:=true use_scan_filter:=false
```

**③ 로봇 운전하며 맵 작성** (새 터미널) — 복도·방을 돌며 루프 닫기

```bash
ros2 run teleop_twist_keyboard teleop_twist_keyboard
```

**④ 맵 저장**

```bash
ros2 run nav2_map_server map_saver_cli -f ~/tribo_map
```

**⑤ Nav2 자율주행** (SLAM 종료 후)

> **⚠️ 그 전에 — `tribo_navigation` 을 빌드했는지 확인할 것.**
>
> `$(find-pkg-share tribo_navigation)` 은 **install 사본**을 가리킵니다. 이 패키지의
> install 이 심링크가 아닌 복사본이면 `config/nav2_params.yaml` 을 아무리 고쳐도
> 노드에는 안 먹습니다. 실제로 2026-08-21 에 install 사본이 **5주 스테일**이라
> `robot_radius: 0.22` 로 돌고 있었고(전폭 0.78 m 로봇을 반경 0.22 m 원으로 충돌
> 검사), `RotationShimController` 도 통째로 빠져 있어 **Nav2 주행 중 벽에 부딪혔습니다.**
>
> ```bash
> rm -rf build/tribo_navigation install/tribo_navigation
> colcon build --packages-select tribo_navigation --symlink-install
> ```
>
> 뜬 뒤에는 반드시 **라이브 파라미터로 검증**하세요. 파일을 보는 것으로는 부족합니다.
>
> ```bash
> ros2 param get /global_costmap/global_costmap footprint
> ```

```bash
ros2 launch tribo_navigation bringup_launch.xml \
  map:=$HOME/tribo_map.yaml use_sim_time:=true use_rviz:=false

# 다른 터미널 — RViz (Nav2 Goal 로 목표 지정)
ros2 launch tribo_navigation nav2_view.launch.xml
```

**⑥ sim 전용 파라미터로 튜닝하고 싶을 때**

`nav2_params.yaml` 은 sim 과 실로봇이 **같이 쓰는 파일**입니다. sim 을 튜닝하면 실주행
설정이 그대로 바뀝니다. 실로봇을 건드리지 않고 sim 만 조정하려면 오버레이를 쓰세요.

```bash
ros2 launch tribo_gazebo nav_sim.launch.py map:=$HOME/tribo_map.yaml
```

`tribo_gazebo/params/nav2_sim_overlay.yaml` 에 적은 키만 base 위에 덮어씌워지고
나머지는 그대로 물려받습니다(런치 시점 깊이 병합). 병합 결과는
`/tmp/tribo_nav2_sim_merged.yaml` 에 남으니 열어서 확인할 수 있습니다.
오버레이는 기본이 비어 있어 base 와 완전히 동일하게 동작합니다.

> **시뮬 주의점**
> - 시뮬에서는 **항상 `use_sim_time:=true`** (안 주면 TF 시간 불일치로 SLAM/Nav 깨짐).
> - `laser_filters`는 시뮬에서도 **필수**입니다(`sudo apt install ros-jazzy-laser-filters`). SLAM·nav2가 `/scan_filtered`를 구독하므로 `use_scan_filter:=false`로는 우회되지 않습니다 — 필터를 끄면 그 토픽을 발행하는 노드가 없어져 스캔이 아예 안 들어옵니다.
> - SLAM과 Nav2는 **동시에 띄우지 말 것** (맵 작성 → 저장 → 종료 → Nav2 순서).

> **⚠️ URDF/xacro 편집 함정 — 주석에 "콜론+공백" 금지**
>
> `tribo_description/urdf/*.xacro` 주석에 `단위: m` 같은 **콜론+공백(`: `)** 패턴을 넣으면, robot_description이 YAML로 파싱되며 `yaml.safe_load() failed`로 robot_state_publisher가 죽습니다. `단위 m`, `보정식 - ...` 처럼 콜론을 빼세요.

#### 시뮬 회전 odom 재보정 (필요 시)

스키드 스티어 회전 슬립이 바뀌면 `gazebo_control.xacro`의 `wheel_separation`을 다시 맞춥니다. sim 의 DiffDrive 플러그인은 완벽한 ground-truth odom 을 내므로, 제자리 회전 명령을 주고 회전한 실제 각도(RViz 에서 로봇 자세, 또는 gz `/world/.../pose`)와 `/odom` yaw 변화를 비교:

```bash
ros2 topic pub -r 20 /cmd_vel geometry_msgs/msg/Twist "{angular: {z: 0.6}}"
ros2 topic echo /odom --field twist.twist.angular.z   # RViz 가 쓰는 값
# 새 값 = 현재값 * (실제 각속도 / odom 각속도)
```

---

### 7-6. 로봇 LCD 표시 — 명령 모음

로봇 화면에 무엇을 띄울지에 따라 세 가지입니다. **세 개를 동시에 켜면 같은 화면을 두고 다투므로 하나만 쓰세요.**

| 용도 | 명령 | 배율 조정 |
|---|---|---|
| 카메라 영상 | `launch_camera_on_lcd.sh` | 화면 꽉 채움(고정) |
| 매핑 중인 맵 | `map_building.launch.py` (자동 포함) | 맵이 자라면 **매 프레임 자동** |
| Nav2 주행 | `bringup_launch.xml` (자동 포함) | 기동 시 **맵 크기로 자동** |

**카메라 (컬러)**

```bash
ros2 launch realsense2_camera rs_launch.py
```

```bash
~/tribo_ws/src/tribo/tribo_bringup/scripts/launch_camera_on_lcd.sh
```

**카메라 (depth)** — `enable_depth:=false` 로 띄우면 화면이 검게만 보입니다(5-5-6 참고).

```bash
~/tribo_ws/src/tribo/tribo_bringup/scripts/launch_camera_on_lcd.sh /camera/camera/depth/image_rect_raw
```

**매핑** — 별도 명령 없이 함께 뜹니다.

```bash
ros2 launch tribo_navigation map_building.launch.py
```

**Nav2** — 별도 명령 없이 함께 뜹니다.

```bash
ros2 launch tribo_navigation bringup_launch.xml map:=/home/tribo/my_map.yaml set_initial_pose:=false
```

#### 끄기

LCD 앞이라면 뷰어 위에서 `q` 또는 `ESC`. SSH 라면:

```bash
pkill -f "lcd_camera_view[.]py"
```

```bash
pkill -f "lcd_map_view[.]py"
```

```bash
pkill -f "ros2 launch tribo_navigation"
```

> 대괄호(`[.]`)는 오타가 아닙니다. `pkill -f` 는 **자기 자신의 명령줄도 검사**하므로 패턴이 그대로 들어 있으면 스스로를 죽여 뒤 명령이 실행되지 않습니다.
>
> `pkill -f "ros2 launch tribo_navigation"` 은 **다른 사람이 띄운 launch 도 함께 죽입니다.** 같은 기체를 둘이 조작할 때 상대의 실행을 끊어 "맵이 겹친다"처럼 보이는 증상을 만듭니다(실제로 겪음).

#### 화면이 꺼져 있을 때

절전 설정(5-5-6)을 끄기 **전에** 이미 꺼졌다면 설정만으로는 켜지지 않습니다.

```bash
export DBUS_SESSION_BUS_ADDRESS=unix:path=/run/user/1000/bus
```

```bash
busctl --user call org.gnome.ScreenSaver /org/gnome/ScreenSaver org.gnome.ScreenSaver SetActive b false
```

#### 공통 전제

- **LCD 에 GNOME 세션이 로그인돼 있어야** 합니다(자동 로그인이면 부팅만으로 충족).
- **`wmctrl` 이 필요합니다.** 없으면 경고를 찍고 창이 작게 뜹니다 — `sudo apt install -y wmctrl`.
- `XAUTHORITY` 는 mutter 가 매 부팅마다 임의 접미사로 새로 만들므로 경로를 하드코딩하면 재부팅 후 깨집니다. 스크립트가 글롭으로 최신 파일을 찾습니다.

---

## 8. 주요 파라미터 파일

| 파일 | 설명 |
|---|---|
| `tribo_bringup/config/bringup.yaml` | 모터별 gain, PWM 최소듀티, cmd 안전(deadzone/timeout) — 시리얼 `port`는 launch가 해석(5-3) |
| `tribo_bringup/config/motor_calib.yaml` | **로봇별** 오버라이드 — 모터 gain(8-1) + 회전 선형화 계수(8-3). **gitignore** — 커밋 안 함. 있으면 launch가 bringup.yaml 뒤에 로드해 덮어씀 |
| `tribo_bringup/udev/99-tribo-serial.rules` | USB 장치 고정 이름 udev 규칙 (`/dev/tribo_base`, `/dev/tribo_lidar`) |
| `tribo_bringup/config/robot_geom.yaml` | 공유 기구 파라미터 (track_width, wheel_radius, ticks_per_rev) |
| `tribo_odom/config/odom.yaml` | 오도메트리 파라미터 |
| `tribo_navigation/config/nav2_params.yaml` | Nav2 설정 |

### ⚠️ 캘리브 순서와 전제조건 — 먼저 읽으세요

**캘리브는 반드시 아래 순서로 하세요. 순서를 바꾸면 앞 단계의 오류가 뒤 단계의 측정값을 오염시켜, 멀쩡한 설정을 범인으로 오해하게 됩니다.**

| 순서 | 항목 | 로봇 자세 | 왜 이 순서인가 |
|---|---|---|---|
| **8-1** | 모터 게인 (`motor_calib`) | **바퀴 들기** (받침대) | 좌우 모터 불균형이 남아 있으면 회전이 방향별로 비대칭이 되어 8-2 의 측정이 통째로 무의미해진다 |
| **8-2** | 회전 odom (`track_width` 수동) | **바닥** | 게인이 잡힌 뒤라야 슬립이 재현 가능해지고, 그때 비로소 유효 track 이 의미를 갖는다 |
| **8-3** | 회전 선형화 (`rot_lin_*`) | **바닥** | 8-2 로 odom 이 맞아야 "실제 회전량"을 신뢰할 수 있고, 그래야 명령-실제 응답을 피팅할 수 있다 |

> **자동 캘리브 도구 `rotation_calib` 은 2026-07-15 제거되었습니다.** 이 도구는 IMU 자이로를 "실제 회전량"의 기준으로 삼았는데, 이 보드의 자이로가 **지속 회전 약 2.4초(≈24°) 후 0으로 죽는** 결함이 확인되어(라이다 독립 측정으로 검증) IMU·EKF 를 워크스페이스 전체에서 제거했습니다. 회전 yaw 는 이제 **휠 오도메트리 단독**(`odom_publisher` → `/odom` + TF)으로만 추정하며, 그 정확도는 `track_width` 한 값에 달려 있습니다. 8-2·8-3 은 그래서 라이다로 실제 회전각을 재는 수동 절차로 바뀌었습니다.

**모든 캘리브의 공통 전제 — 배터리 11V 이상.** 전압이 낮으면 모터 토크가 스크럽 마찰을 못 이겨 **바퀴만 헛돌고 로봇은 안 돕니다.** 저전압에서 측정하면 `track_true` 가 3 m 대까지 튀는 쓰레기값이 나와 방금 잡은 올바른 게인을 되돌릴 뻔한 사례가 있었습니다. **측정 전 반드시 전압부터 확인하세요.**

```bash
ros2 topic echo /battery --once     # voltage 11V 이상인지 먼저 확인
```

---

### 8-1. 모터 게인 자동 캘리브레이션 (실로봇) &nbsp;·&nbsp; 🤖 로봇 전용

로봇마다 4개 모터(m1=FL, m2=RL, m3=RR, m4=FR)의 개체 편차가 있어, 같은 PWM에도 바퀴 속도가 달라 직진이 틀어집니다. `motor_calib` 노드가 **전진 시 4모터의 엔코더 tick rate를 측정 → 가장 느린 모터에 맞춰 나머지 gain을 낮춤**을 반복해, 불균형이 임계치(기본 5%) 미만으로 **수렴할 때까지** 자동 보정합니다.

**결과는 로봇별 파일 `config/motor_calib.yaml`에 저장**되고(gitignore — 값이 로봇마다 다르므로 커밋하지 않음), `bringup.launch.py`가 이 파일이 있으면 `bringup.yaml` 뒤에 오버라이드로 로드합니다. 소스를 고쳐도 install 복사본은 별개라(install config 미반영 함정), 스크립트가 매 반복 `colcon build`로 install에 반영합니다.

```bash
# ⚠️ 반드시 바퀴를 들고(로봇을 받침대에 올려) 실행 — 모터가 실제로 회전합니다.
export ROS_DOMAIN_ID=20
source /opt/ros/jazzy/setup.bash && source ~/tribo_ws/install/setup.bash
bash ~/tribo_ws/src/tribo/tribo_bringup/scripts/motor_calib_converge.sh
# 반복 상한/허용오차 조정: MAX_ITER=8 TOL=0.05 를 앞에 붙여 실행
```

스크립트는 매 반복마다 `bringup 기동 → /encoder_raw 대기 → 캘리브 시퀀스(모터 회전) → gain 기록 → 재빌드 → 재시작`을 수행하고, 끝에 **자동 진단**을 출력합니다:

| VERDICT | 의미 | 조치 |
|---|---|---|
| `PASS` | 불균형 < TOL 수렴 | 완료. 바닥에서 직진성 확인 후 커밋 |
| `NOT_CONVERGED` | 아직 임계 초과(문제 아님) | 재실행하면 **저장된 gain에서 이어서** 수렴(모터 비선형 때문에 여러 번 필요). 반영은 재부팅 후에도 유지됨 |
| `FAIL_STUCK m{X}` | 모터 X가 거의 안 돎 | `pwm_min_percent` 상향 또는 배선/기계 저항 점검 (gain으로 해결 불가) |
| `FAIL_SIGN m{X}` | 모터 X 회전 방향 반대 | `bringup.yaml`의 `invert_m{X}` 토글 후 재실행 |

수렴 후 확인:
```bash
ros2 param get /tribo_bringup gain_m1     # motor_calib.yaml 값이 나오면 반영됨
```

> - **바퀴를 든 채로는 회전 관련 추천(`turn_scale`, `gain_*_rev_factor`)이 무의미**합니다 — 로봇이 실제로 안 돌아 `yaw_rate≈0`이라 값이 터무니없이 나옵니다. **스크립트가 `turn_scale = 224.8` 같은 값을 추천하는 건 0으로 나눈 것이니 절대 적용하지 마세요.** 직진 gain(`gain_m*`)만 신뢰하고, 회전 보정은 바닥에서 8-2·8-3으로 하세요.
> - 전진 시 엔코더가 음수로 찍히는 로봇에서는 레거시 로그에 `[직진] 좌/우 부호` 경고가 뜰 수 있으나, 자동 진단 `VERDICT`가 `FAIL_SIGN`이 아니면 **정상**(거짓 경고)입니다.
> - "가장 느린 모터 기준"이라 빠른 모터가 많이 눌려 **최고 직진 속도가 느린 모터 수준으로 제한**됩니다. 균형 대신 속도를 더 살리려면 기준을 평균으로 바꾸는 옵션을 추가할 수 있습니다.

### 8-2. 회전 odom 캘리브레이션 (실로봇) &nbsp;·&nbsp; 바닥에 내려놓고

> **선행 조건: 8-1(모터 게인)이 끝나 있어야 합니다.** 게인이 이 기체 것이 아니면 아래 측정은 의미가 없습니다.

4륜 스키드는 제자리 회전 시 바퀴가 옆으로 헛돌아(스크럽) 휠 odom 회전이 실제보다 과대 적분됩니다. 그래서 odom 은 물리 트랙이 아니라 **슬립을 흡수한 "유효 트랙"**(`track_width`)을 써야 합니다. IMU 를 제거했으므로 "실제 회전량"의 기준은 **라이다**입니다 — 로봇을 제자리 회전시키며 연속 `/scan` 을 각도축에서 상관(cross-correlation)시키면 자이로 없이 실제 회전각이 나옵니다(스크럽·헛돎에 영향받지 않음).

측정·조정 절차:

1. 로봇을 특징이 있는 벽·기둥이 보이는 곳에 놓고 bringup 실행.
2. 제자리 회전(`ros2 topic pub /cmd_vel ... angular.z: 0.4`)시키며 **라이다 실제 회전각**과 **`/odom` yaw 변화**를 같은 시간 동안 비교.
3. `track_width_new = track_width_cur × (라이다 실제 회전 / odom yaw 회전)` 으로 갱신.
4. `bringup.launch.py` 의 `_odom_common_params["track_width"]` 에 반영 후 재측정 → `/odom` 회전이 라이다와 **±3% 이내로 일치**하면 성공.

> **현재 이 기체는 `track_width: 0.838` 고정** (v2 실측값). 라이다 실측 대비 휠이 회전을 ~5% 적게 보는 정황이 있어 실제로는 ~0.885 방향이지만, 재캘리브 도구를 제거하고 값을 고정했습니다. 필요 시 위 절차로 이 한 값만 조정하세요.

> - **`제어 비대칭`(CW/CCW 회전량 차)이 큰데 odom 스케일은 맞을 수 있습니다.** 둘은 다른 문제입니다 — 전자는 모터(로봇이 한쪽으로 더 빨리 돎, 8-1 재확인), 후자는 `track_width`(odom 스케일)입니다.
> - 슬립 변동이 심해 방향마다 `track_true` 가 크게 다르면 단일 고정 트랙으로는 한계입니다. 그때는 기계(바퀴 접지·마운트)부터 점검하세요 — 한 바퀴가 뜨면 방향별로 값이 튑니다.

### 8-3. 제자리 회전 선형화 (실로봇) &nbsp;·&nbsp; 바닥에 내려놓고

> **선행 조건: 8-2 가 끝나 있어야 합니다.** odom 이 맞아야 "실제 회전량"을 믿을 수 있습니다.

개루프 PWM 에서 회전 응답은 **비례가 아니라 아핀**입니다:

```
실제_wz ≈ rot_lin_offset + rot_lin_slope × 명령_wz
```

`offset` 은 PWM 바닥(`rotate_pwm_min`)이 만드는 **최소 회전속도**입니다. 이것 때문에 **`turn_scale` 같은 순수 게인으로는 절대 못 맞춥니다** — offset 을 지울 수 없어 필요한 배율이 명령마다 달라집니다(v2 에선 1.8~3.8). 그래서 bringup 이 **식을 역으로 풀어** 목표 wz 를 내부 wz 로 변환합니다.

**계수 측정** — `angular_speed` 를 바꿔가며 명령 wz 대비 **실제 wz**(라이다 스캔 상관으로 측정, 8-2 와 동일 방식)를 모읍니다. 각 속도에서 제자리 회전시키고 `라이다 실제 회전각 / 회전 시간` 으로 실제 wz 를 구해 `(명령_wz, 실제_wz)` 쌍을 쌓습니다.

`실제_wz = offset + slope × 명령_wz` 로 직선 피팅해 `bringup.yaml`(또는 로봇별 `motor_calib.yaml`)에 넣습니다. 명령을 계속 올려도 실제가 더 안 늘어나는 지점이 **물리적 회전 천장**이며, `rot_lin_max_wz` 는 그보다 여유 있게 아래로 잡습니다.

```yaml
rot_lin_enable: true
rot_lin_offset: 0.186     # rad/s — 최소 회전속도 (v2 실측)
rot_lin_slope: 0.216      # (v2 실측)
rot_lin_max_wz: 0.55      # 실측 천장 ~0.6 보다 아래
rot_lin_vx_max: 0.02      # |vx| 가 이 이하일 때만 적용 (제자리 회전)
```

**검증** — 전 구간에서 `실제/명령`이 1.0 근처로 **평평**해야 합니다 (v2: 0.25→1.02, 0.35→1.04, 0.45→1.04, 0.55→1.03).

> - **⚠️ 계수는 기체마다 다릅니다.** `gain_m*` 과 마찬가지로 **로봇별 `motor_calib.yaml` 에서 오버라이드**하세요. 양산 기체에 v2 값을 그대로 쓰면 또 틀어집니다.
> - **제자리 회전에만 적용됩니다**(`|vx| <= rot_lin_vx_max`). 전진 중 선회는 스크럽 조건이 달라 같은 식이 성립하지 않으므로 손대지 않습니다 — 직진 거동은 영향받지 않습니다.
> - **최소 회전속도는 없앨 수 없습니다.** 그보다 느리게 명령해도 로봇은 최소 속도로 돕니다(0 으로 죽이면 Nav2 가 각도 오차를 못 줄여 수렴하지 못하므로 일부러 그렇게 둡니다). **Nav2 의 회전 하한(`min_rotational_vel`)을 이 값 위로** 두세요.
> - **Nav2 의 회전 상한도 실측 천장에 맞추세요.** 낼 수 없는 속도를 명령하면 Nav2 의 소요시간 예측이 어긋납니다. v2 기준: `velocity_smoother` theta 0.55, RPP `rotate_to_heading_angular_vel` 0.5, `behavior_server` `max_rotational_vel` 0.5.

#### 보드 속도 폐루프(`use_motion_mode: true`)를 왜 안 쓰는가

`tribolib` 에 `set_motion()`(보드 PID) 이 있어 시도해볼 수 있지만, **tribo v2 에서는 직진이 깨집니다.** 회전은 정확해지나(0.3 rad/s → 실제 0.30), 직진은 **명령을 0.025~0.45 m/s 로 18배 바꿔도 실제가 0.29~0.37 m/s 로 사실상 단일 속도**가 됩니다. Nav2 는 저속 접근이 필수라 쓸 수 없습니다. (`car_type` 설정이 이 기체 기구학과 안 맞는 것으로 의심되나 미확인.) **개루프 + 8-3 선형화가 현재 유일하게 성립하는 조합입니다.**

---

## 9. 문제 해결

| 증상 | 확인 |
|---|---|
| SSH 접속 `Connection refused` | ① 로봇에서 `sudo systemctl status ssh` 확인, 없으면 `openssh-server` 설치 (3-2). ② **옛 IP로 접속하고 있지 않은지 확인** — DHCP로 IP가 바뀐 뒤 그 IP를 *다른 기기*가 가져가면 `timed out`이 아니라 `refused`가 뜬다. 로봇에서 `hostname -I`로 현재 IP를 다시 확인할 것 (3-4-1) |
| 접속은 되는데 **엉뚱한 로봇**에 붙은 것 같음 | 기체들이 hostname이 같아 생기는 문제. `grep -m1 "^Serial" /proc/cpuinfo` 로 Pi 시리얼을 확인해 어느 기체인지 특정 (3-4-1) |
| SSH `REMOTE HOST IDENTIFICATION HAS CHANGED` / `Host key verification failed` | 같은 IP에 새 로봇을 올린 경우. PC에서 `ssh-keygen -R <robot-ip>`로 옛 호스트키 제거 후 재접속 (3-5) |
| `could not open port ...` | `dialout` 그룹 추가 후 재로그인 했는지(5-1), 보드가 연결됐는지 |
| `ModuleNotFoundError: serial` | `sudo apt install python3-serial` |
| PC에서 publish해도 로봇이 안 움직임 | PC·로봇 `ROS_DOMAIN_ID` 일치 여부 |
| 보드·라이다가 서로 포트를 뺏음 (`multiple access` / 라이다 `OPERATION_TIMEOUT`) | udev 규칙 설치(5-2). 미설치 시에도 launch가 by-id로 해석하지만, udev 설치를 권장 |
| bringup 중복 실행 시 `multiple access on port` | `bringup.launch.py`가 시작 시 이전 인스턴스를 자동 정리함. 끄려면 `TRIBO_AUTOCLEAN=0` |
| 라이다 `/scan` 안 나옴 | `ls /dev/tribo_lidar`(또는 by-id) 존재 여부, 라이다 전원/USB 연결 |
| `sllidar_ros2` 빌드 누락 | `git submodule update --init --recursive` 후 재빌드 |
| Nav2 `get_state service is not available! Aborting bringup` | CPU 거버너를 `performance`로(5-4). Pi5에서 거의 항상 이 원인. RViz는 PC에서(`use_rviz:=false`) |
| nav/bringup을 Ctrl-C로 껐는데 노드가 안 죽고 남음 | `ros2 launch`는 Ctrl-C 한 번만 처리(이후 무시), sllidar는 종료 느림. 재실행 전 `pkill -9 -f 'ros-args'`로 잔여 노드 정리 (bringup auto-clean은 nav 노드는 안 건드림) |
| `odom_publisher: No package metadata was found for tribo-odom` | entry point 추가 후 증분 빌드 깨짐. `rm -rf build/tribo_odom install/tribo_odom src/tribo/tribo_odom/tribo_odom.egg-info && colcon build --packages-select tribo_odom --symlink-install` |

---

## 10. 하드웨어 (3D 설계 파일)

Tribo의 3D 설계 파일(1차/최종 설계 파일, STEP, STL)은 [`hardware`](./hardware) 폴더에 있습니다. 자세한 내용은 해당 폴더의 [README](./hardware/README.md)를 참고하세요.

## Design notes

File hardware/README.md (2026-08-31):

# Tribo 설계 자료

Tribo 로봇의 3D 설계 파일 및 3D 프린팅용 파일 모음입니다.

- [1차설계파일](./1차설계파일)
- [최종설계파일](./최종설계파일)
- [step](./step)
- [stl](./stl)
- [가공용 도면](./가공용%20도면)

## 1차설계파일

- 1차 Tribo 설계 파일입니다.
- 최종 설계 파일에서 참조하고 있는 모델들이 포함되어 있어서, **최종설계파일과 함께 다운로드**해야 정상적으로 열립니다.

## 최종설계파일

- 26년 8월 기준으로 업데이트된 Tribo 설계 파일입니다.
- 모터 커버와 LCD 모니터 거치대는 아직 최신화되어 있지 않습니다.
- 최종 어셈블 파일은 `Tribo_Trolly_withArm`, `Tribo_Trolly_withCamera`에 저장되어 있습니다.
    - **Tribo_Trolly_withArm**: Tribo에 양팔 로봇을 장착시킨 버전
    - **Tribo_Trolly_withCamera**: Tribo에 카메라만 장착시킨 버전

## step

- Tribo의 STEP 파일이 담겨져 있는 폴더입니다.

## stl

- Tribo의 3D 프린팅을 위한 STL 파일들이 담겨져 있는 폴더입니다.

### 3D 프린팅 부품 리스트

| 부품 | 설명 |
| --- | --- |
| `Bearing_Spacer_V3` | 베어링과 프로파일을 체결하기 위한 스페이서. 스페이서별로 높이를 조금 더 높인 버전들이 추가로 있습니다. |
| `camerabase_set` | Tribo에 카메라를 장착시키기 위한 베이스. `camerabase_up`, `camerabase_down`을 각각 프린트해서 조립해야 합니다. ⚠️ 출력 시 본체보다 서포터가 더 많이 출력되는 것을 확인할 수 있습니다. |
| `Gimbal_Neck` | 카메라 베이스에 연결되는 넥(neck) |
| `D435_거치대` | 넥(neck)에 D435 카메라를 고정시키기 위한 거치대 |
| `LCD_Bottom_Cover` | LCD 모니터 케이스의 후면 케이스 |
| `LCD_Upper_Cover` | LCD 모니터 케이스의 전면 케이스 |
| `LCD_Mount_20degrees_V3` | 프로파일과 LCD 케이스를 45도 각도로 연결하기 위한 거치대 |
| `Motor_Cover_LH`, `Motor_Cover_RH` (V3) | 외부로 노출된 모터를 보호하기 위한 케이스 (좌/우) |

## 가공용 도면

- 가공할 때 요청하기 위해 별도로 만든 도면 파일입니다.

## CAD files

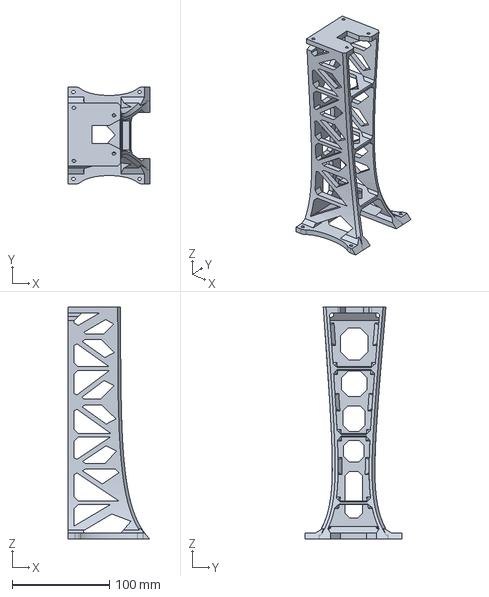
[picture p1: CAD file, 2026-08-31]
hardware/step/Gimbal_Neck.step
84.0 x 100.0 x 239.0 mm

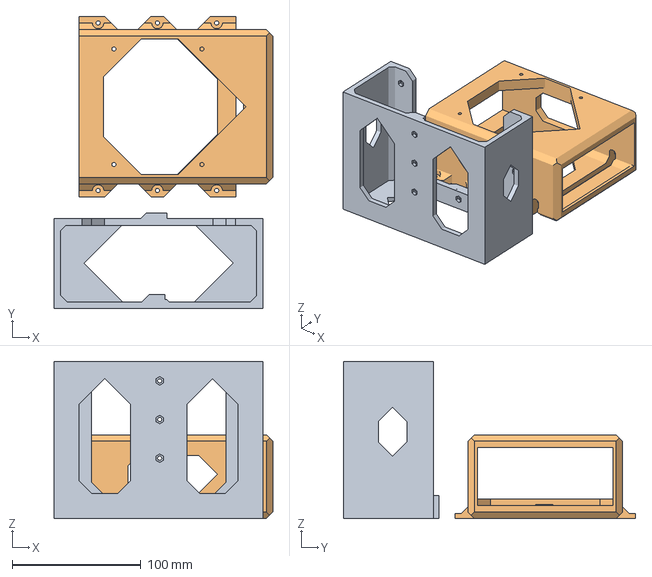
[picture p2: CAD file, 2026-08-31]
hardware/stl/camerabase_set.3mf
169.6 x 226.5 x 121.8 mm
camerabase_down.stl
camerabase_up.stl

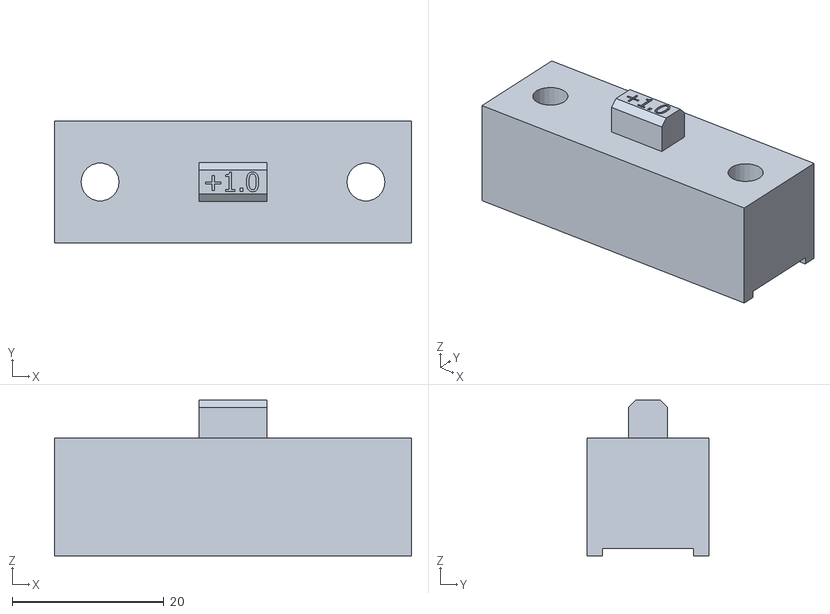
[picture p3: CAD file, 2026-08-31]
hardware/stl/베어링 서포터/Bearing Spacer_V2_1mm.stl
47.0 x 16.0 x 20.5

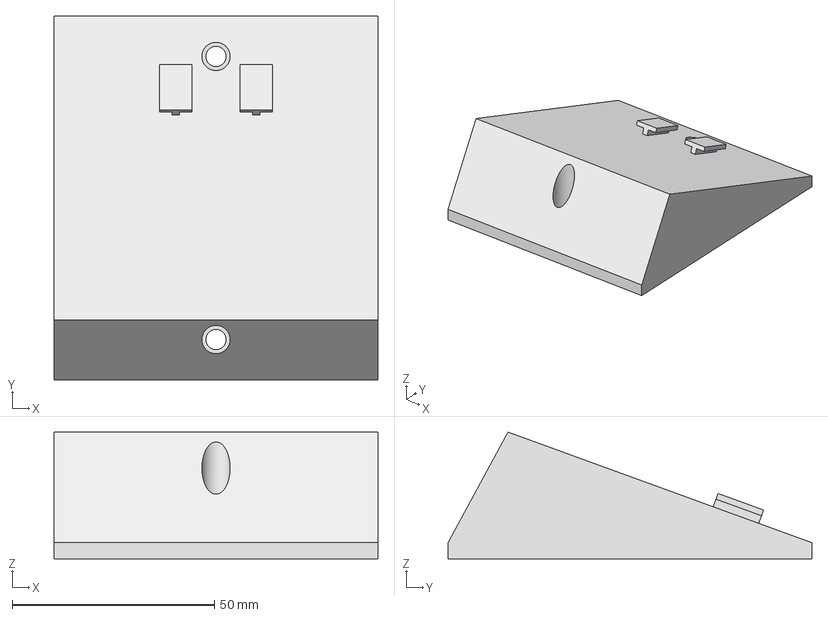
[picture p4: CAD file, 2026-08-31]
hardware/step/LCD_Mount_20degrees.stp
80.0 x 90.0 x 31.4 mm

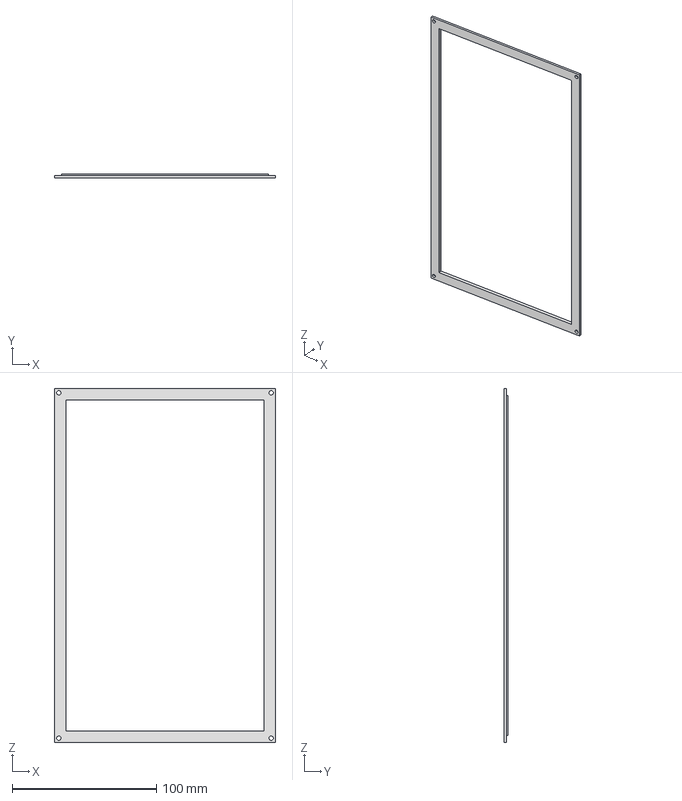
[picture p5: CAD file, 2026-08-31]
hardware/step/LCD_Upper_Cover.stp
153.0 x 3.10 x 245.0 mm

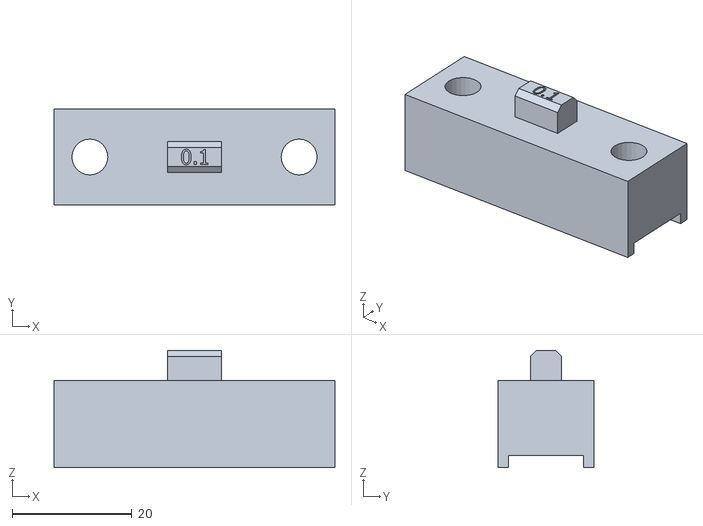
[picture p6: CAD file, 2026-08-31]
hardware/stl/Bearing Spacer_V3_0.1mm.stl
47.0 x 16.0 x 19.6

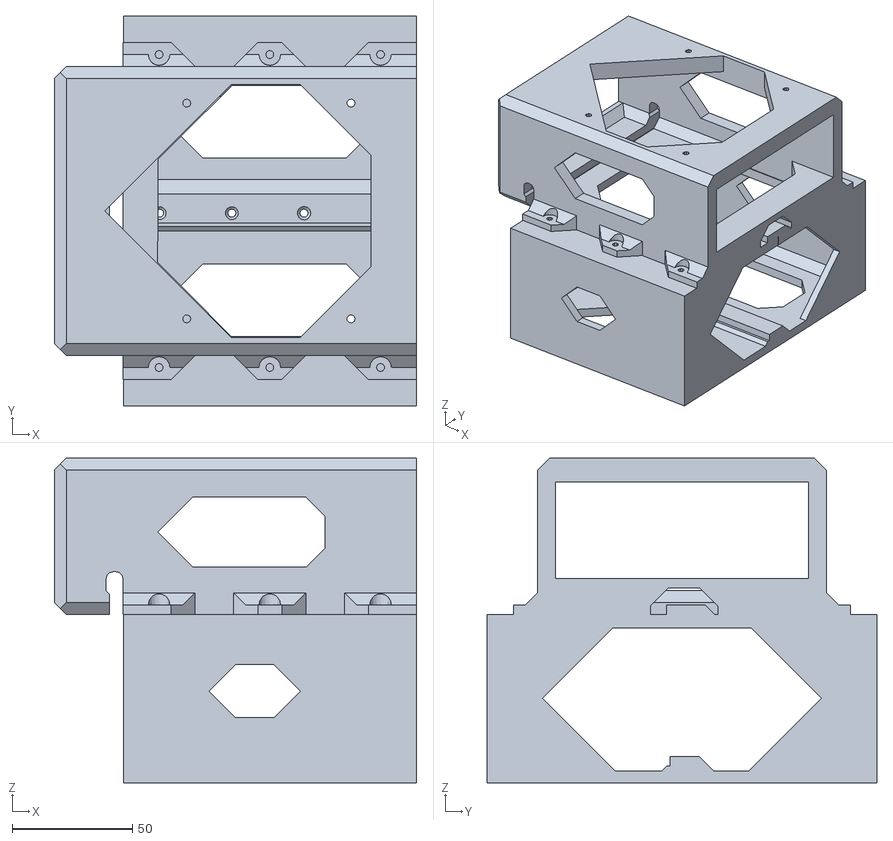
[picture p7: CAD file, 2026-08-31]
hardware/step/Camera_Base_OnlyTrolly.stl
150.5 x 162.0 x 135.0

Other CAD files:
hardware/가공용 도면/아크릴/Acryil_Plate_Outer_600X460X5t_Cover.dwg
hardware/가공용 도면/알루미늄플레이트/AL_Plate_Outer_600X500X2t_UpperCover.dwg
hardware/stl/Bearing Spacer_V3_0.5mm.stl
hardware/stl/베어링 서포터/Bearing Spacer_V3_0.7mm.stl
hardware/가공용 도면/아크릴/Acryril_Plate_Outer_600X80X5t_ChargeHole.dwg
hardware/가공용 도면/알루미늄플레이트/AL_Plate_Outer_600X460X2t_DriveTrain.dwg
hardware/stl/베어링 서포터/Bearing Spacer_V3_0.5mm.stl
hardware/가공용 도면/아크릴/Acyril_Plate_Outer_460X80X5t(2개 가공).dwg
hardware/stl/베어링 서포터/Bearing Spacer_V3_0.3mm.stl
hardware/가공용 도면/아크릴/Acryril_Plate_Outer_600X80X5t.dwg
hardware/1차설계파일/035armbase.step-1.step.STEP.step.STEP.ipt
hardware/1차설계파일/035armbase.step.step.STEP.step.STEP.iam
hardware/1차설계파일/2.0_PIN_HEADER.STEP.STEP.step.STEP.ipt
hardware/1차설계파일/2xUSB_2.0_PORT.STEP.STEP.step.STEP.ipt
hardware/1차설계파일/2xUSB_3.0_PORT.STEP.STEP.step.STEP.ipt
hardware/1차설계파일/3.0_PIN_HEADER_10.STEP.STEP.step.STEP.ipt
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

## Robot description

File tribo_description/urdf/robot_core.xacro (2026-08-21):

<?xml version="1.0"?>
<robot name="tribo" xmlns:xacro="http://www.ros.org/wiki/xacro">

    <xacro:include filename="inertial_macros.xacro"/>

    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
    <xacro:property name="wheel_radius" value="0.05"/>
    <xacro:property name="wheel_width" value="0.04"/>
    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
    <xacro:property name="wheel_x" value="0.20"/>   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
    <xacro:property name="wheel_y" value="0.37"/>   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
    <xacro:property name="base_x" value="${2*(wheel_x + wheel_radius)}"/>   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
    <xacro:property name="base_y" value="${2*(wheel_y - wheel_width/2)}"/>  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
    <xacro:property name="base_h" value="0.12"/>   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
    <xacro:property name="base_bottom" value="0.0"/>    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
    <xacro:property name="base_cz" value="${base_bottom + base_h/2}"/>
    <xacro:property name="deck_z" value="${base_bottom + base_h}"/>  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
    <xacro:property name="frame_h" value="0.42"/>   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
    <xacro:property name="post_t" value="0.02"/>   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
    <xacro:property name="frame_inset" value="0.04"/>   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
    <xacro:property name="post_x" value="${base_x/2 - frame_inset - post_t/2}"/>  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
    <xacro:property name="post_y" value="${base_y/2 - frame_inset - post_t/2}"/>  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
    <xacro:property name="top_z" value="${deck_z + frame_h}"/>  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
    <xacro:property name="motor_r" value="0.04"/>
    <xacro:property name="motor_len" value="0.10"/>                           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
    <xacro:property name="motor_inset" value="0.005"/>
    <xacro:property name="motor_outer" value="${wheel_y - wheel_width/2 - motor_inset}"/>
    <xacro:property name="motor_cy" value="${motor_outer - motor_len/2}"/>

    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
    <xacro:property name="lidar_x" value="0.16"/>
    <xacro:property name="camera_x" value="0.17"/>

    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
    <link name="base_link"/>

    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
    <link name="chassis">
        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
        <xacro:inertial_box mass="3.0" x="${base_x}" y="${base_y}" z="${base_h}">
            <origin xyz="0 0 ${base_cz}" rpy="0 0 0"/>
        </xacro:inertial_box>
    </link>

    <joint name="chassis_joint" type="fixed">
        <parent link="base_link"/>
        <child link="chassis"/>
        <origin xyz="0 0 0"/>
    </joint>

    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
    <link name="front_left_wheel">
        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
        <xacro:inertial_cylinder mass="0.1" length="${wheel_width}" radius="${wheel_radius}">
            <origin xyz="0 0 0" rpy="0 0 0"/>
        </xacro:inertial_cylinder>
    </link>
    <joint name="front_left_wheel_joint" type="continuous">
        <parent link="base_link"/>
        <child link="front_left_wheel"/>
        <origin xyz="${wheel_x} ${wheel_y} 0" rpy="-${pi/2} 0 0"/>
        <axis xyz="0 0 1"/>
    </joint>

    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
    <link name="front_right_wheel">
        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
        <xacro:inertial_cylinder mass="0.1" length="${wheel_width}" radius="${wheel_radius}">
            <origin xyz="0 0 0" rpy="0 0 0"/>
        </xacro:inertial_cylinder>
    </link>
    <joint name="front_right_wheel_joint" type="continuous">
        <parent link="base_link"/>
        <child link="front_right_wheel"/>
        <origin xyz="${wheel_x} ${-wheel_y} 0" rpy="${pi/2} 0 0"/>
        <axis xyz="0 0 -1"/>
    </joint>

    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
    <link name="rear_left_wheel">
        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
        <xacro:inertial_cylinder mass="0.1" length="${wheel_width}" radius="${wheel_radius}">
            <origin xyz="0 0 0" rpy="0 0 0"/>
        </xacro:inertial_cylinder>
    </link>
    <joint name="rear_left_wheel_joint" type="continuous">
        <parent link="base_link"/>
        <child link="rear_left_wheel"/>
        <origin xyz="${-wheel_x} ${wheel_y} 0" rpy="-${pi/2} 0 0"/>
        <axis xyz="0 0 1"/>
    </joint>

    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
    <link name="rear_right_wheel">
        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
        <xacro:inertial_cylinder mass="0.1" length="${wheel_width}" radius="${wheel_radius}">
            <origin xyz="0 0 0" rpy="0 0 0"/>
        </xacro:inertial_cylinder>
    </link>
    <joint name="rear_right_wheel_joint" type="continuous">
        <parent link="base_link"/>
        <child link="rear_right_wheel"/>
        <origin xyz="${-wheel_x} ${-wheel_y} 0" rpy="${pi/2} 0 0"/>
        <axis xyz="0 0 -1"/>
    </joint>

    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
    <link name="frame">
        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
        <xacro:inertial_box mass="1.2" x="${2*post_x}" y="${2*post_y}" z="${frame_h}">
            <origin xyz="0 0 ${deck_z + frame_h/2}" rpy="0 0 0"/>
        </xacro:inertial_box>
    </link>

    <joint name="frame_joint" type="fixed">
        <parent link="chassis"/>
        <child link="frame"/>
        <origin xyz="0 0 0"/>
    </joint>

    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
    <link name="lidar_mount">
        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
        <inertial>
            <origin xyz="0 0 0.01" rpy="0 0 0"/>
            <mass value="0.05"/>
            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
        </inertial>
    </link>

    <joint name="lidar_mount_fixed_joint" type="fixed">
        <parent link="chassis"/>
        <child link="lidar_mount"/>
        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
        <origin xyz="${lidar_x} 0.0 ${deck_z}" rpy="0 0 0"/>
    </joint>

    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
    <link name="laser_link">
        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
        <inertial>
            <origin xyz="0 0 0" rpy="0 0 0"/>
            <mass value="0.2"/>
            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
        </inertial>
    </link>

    <joint name="laser_link_fixed_joint" type="fixed">
        <parent link="lidar_mount"/>
        <child link="laser_link"/>
        <origin xyz="0.0 0.0 0.05" rpy="0 0 ${pi}"/>
    </joint>

    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
    <link name="camera_link">
        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
        <inertial>
            <origin xyz="0 0 0" rpy="0 0 0"/>
            <mass value="0.05"/>
            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
        </inertial>
    </link>

    <joint name="camera_joint" type="fixed">
        <parent link="frame"/>
        <child link="camera_link"/>
        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
        <origin xyz="${camera_x} 0 ${deck_z + 0.32}" rpy="0 0 0"/>
    </joint>

    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
    <link name="camera_link_optical"/>
    <joint name="camera_optical_joint" type="fixed">
        <parent link="camera_link"/>
        <child link="camera_link_optical"/>
        <origin xyz="0 0 0" rpy="${-pi/2} 0 ${-pi/2}"/>
    </joint>

</robot>

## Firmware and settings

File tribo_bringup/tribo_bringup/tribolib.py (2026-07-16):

#!/usr/bin/env python3
# coding: utf-8

import struct
import time
import serial
import threading
from enum import IntEnum, auto
from typing import Tuple, Optional, Callable


class OpCode(IntEnum):
    """보드 펌웨어가 사용하는 기능 코드(opcode) 정의."""
    AUTO_REPORT      = 0x01
    BEEP             = 0x02
    PWM_SERVO        = 0x03
    PWM_SERVO_ALL    = 0x04
    RGB              = 0x05
    RGB_EFFECT       = 0x06

    REPORT_SPEED     = 0x0A
    REPORT_MPU_RAW   = 0x0B
    REPORT_IMU_ATT   = 0x0C
    REPORT_ENCODER   = 0x0D
    REPORT_ICM_RAW   = 0x0E
    RESET_STATE      = 0x0F

    MOTOR_PWM        = 0x10
    CAR_RUN          = 0x11
    MOTION           = 0x12
    SET_MOTOR_PID    = 0x13
    SET_YAW_PID      = 0x14
    SET_CAR_TYPE     = 0x15

    UART_SERVO       = 0x20
    UART_SERVO_ID    = 0x21
    UART_SERVO_TORQUE= 0x22
    ARM_CTRL         = 0x23
    ARM_OFFSET       = 0x24

    AKM_DEF_ANGLE    = 0x30
    AKM_STEER_ANGLE  = 0x31

    REQUEST_DATA     = 0x50
    VERSION          = 0x51

    RESET_FLASH      = 0xA0


class TriboFrameBuilder:
    """
    프레임 생성 유틸리티.
    프로토콜 포맷: [HEAD, DEVICE_ID, LEN, FUNC, ..., CHECKSUM]
    """

    HEAD = 0xFF

    def __init__(self, device_id: int, complement: int, func_code: int):
        self.device_id = device_id
        self.complement = complement
        self.func_code = func_code & 0xFF
        self.payload = []

    def add_u8(self, *values: int) -> "TreeboFrameBuilder":
        for v in values:
            self.payload.append(int(v) & 0xFF)
        return self

    def add_i8(self, *values: int) -> "TreeboFrameBuilder":
        for v in values:
            self.payload.append(struct.pack("b", int(v))[0])
        return self

    def add_i16(self, *values: int) -> "TreeboFrameBuilder":
        for v in values:
            b = struct.pack("<h", int(v))
            self.payload.extend(b)
        return self

    def build(self) -> bytes:
        # LEN = 전체 길이 - 1 (원 라이브러리와 동일 규칙)
        length = 3 + len(self.payload)  # DEVICE_ID, LEN, FUNC + payload
        frame = [self.HEAD, self.device_id, length, self.func_code]
        frame.extend(self.payload)

        checksum = (sum(frame) + self.complement) & 0xFF
        frame.append(checksum)
        return bytes(frame)


class TriboBase:
    """
    Tribo 전용 모터·IMU·엔코더·전압 제어/조회 드라이버 (단일 파일 버전).
    내부적으로 보드의 시리얼 프로토콜을 사용한다.
    """

    # 하드웨어 기본 설정
    _HEAD = 0xFF
    _DEVICE_ID = 0xFC
    _COMPLEMENT = 257 - _DEVICE_ID

    # 주요 차량 타입(필요한 것만 사용)
    CARTYPE_X3      = 0x01
    CARTYPE_X3_PLUS = 0x02
    CARTYPE_X1      = 0x04
    CARTYPE_R2      = 0x05

    _CAR_ADJUST_FLAG = 0x80
    MOTOR_POLARITY = -1  # 보드가 +를 '후진'으로 쓰고 있어서, 로봇 기준으로 의미를 뒤집는다.

    # 수신 스레드 상태
    _uart_thread_state = 0

    def __init__(
        self,
        port: str = "/dev/ttyUSB0",
        baudrate: int = 115200,
        car_type: int = CARTYPE_X3,
        delay: float = 0.002,
        debug: bool = False,
    ) -> None:
        self._debug = debug
        self._delay = delay
        self._car_type = car_type & 0xFF

        # 시리얼 포트 열기
        # timeout=0.1: read 가 주기적으로 리턴해 rx_loop 가 정지 신호(_uart_thread_state)를
        # 확인할 수 있게 한다(없으면 블로킹 read 라 close 시 스레드가 안 빠져나가 race 발생).
        self._ser = serial.Serial(port, baudrate, timeout=0.1)
        if self._ser.is_open:
            print(f"TriboBase: serial opened on {port} @ {baudrate}")
        else:
            raise RuntimeError(f"Failed to open serial port: {port}")

        # IMU, 속도, 엔코더, 전압 상태 캐시
        self._ax = self._ay = self._az = 0.0
        self._gx = self._gy = self._gz = 0.0
        self._mx = self._my = self._mz = 0.0
        self._vx = self._vy = self._vz = 0.0
        self._roll = self._pitch = self._yaw = 0.0
        self._enc_m1 = self._enc_m2 = self._enc_m3 = self._enc_m4 = 0
        self._battery_raw = 0

        # 버전, PID, 기타 상태
        self._version_major = 0
        self._version_minor = 0
        self._version = -1.0

        self._pid_index = 0
        self._kp_raw = self._ki_raw = self._kd_raw = 0

        # Ackermann, car_type read
        self._akm_default_angle = 100
        self._akm_angle_ready = False
        self._akm_servo_id = 0x01

        self._car_type_read = 0

        # arm 관련 간단 상태 (필요 시 확장)
        self._arm_ctrl_enable = True

        # 수신 스레드 핸들
        self._rx_thread: Optional[threading.Thread] = None

    # ---------------------- 공용 유틸 ----------------------

    def _build_frame(self, opcode: OpCode) -> TriboFrameBuilder:
        return TriboFrameBuilder(
            device_id=self._DEVICE_ID,
            complement=self._COMPLEMENT,
            func_code=int(opcode),
        )

    def _send(self, frame: bytes) -> None:
        if self._debug:
            print("TX:", list(frame))
        self._ser.write(frame)
        time.sleep(self._delay)

    # ---------------------- 수신 스레드 ----------------------

    def start_background_reader(self) -> None:
        """보드가 자동 보고하는 데이터를 읽는 백그라운드 스레드 시작."""
        if self._uart_thread_state != 0:
            return

        def rx_loop():
          try:
            self._ser.reset_input_buffer()
            while self._uart_thread_state != 2:
                header = self._ser.read(1)
                if not header:
                    continue
                if header[0] != self._HEAD:
                    continue

                dev_byte = self._ser.read(1)
                if not dev_byte:
                    continue
                dev = dev_byte[0]

                # 기본 프로토콜: 두 번째 헤더 바이트 = DEVICE_ID - 1
                if dev != self._DEVICE_ID - 1:
                    # 프로토콜 다르면 건너뜀
                    continue

                length_b = self._ser.read(1)
                func_b = self._ser.read(1)
                if not length_b or not func_b:
                    continue
                ext_len = length_b[0]
                func = func_b[0]

                # ext_len = 전체 - 1, 그 중 2바이트는 len, func
                data_len = ext_len - 2
                data = bytearray()
                checksum_calc = ext_len + func
                rx_checksum = 0

                while len(data) < data_len:
                    chunk = self._ser.read(1)
                    if not chunk:
                        break
                    data.append(chunk[0])
                    if len(data) == data_len:
                        rx_checksum = data[-1]
                    else:
                        checksum_calc += data[-1]

                if (checksum_calc % 256) != rx_checksum:
                    if self._debug:
                        print("RX checksum error")
                    continue

                self._handle_report(func, data)
          except Exception:
            # close() 로 시리얼이 닫히면 read 가 예외를 낸다. 종료(state==2) 중이면
            # 조용히 빠져나가고, 그 외의 예상치 못한 예외만 표면화한다.
            if self._uart_thread_state != 2:
                import traceback
                traceback.print_exc()

        self._rx_thread = threading.Thread(target=rx_loop, daemon=True)
        self._rx_thread.start()
        self._uart_thread_state = 1
        print("TriboBase: background reader started")

    # ---------------------- 수신 데이터 파싱 ----------------------

    def _handle_report(self, func: int, data: bytearray) -> None:
        """보드에서 자동으로 보내주는 데이터 패킷 처리."""
        try:
            opcode = OpCode(func)
        except ValueError:
            if self._debug:
                print("Unknown report opcode:", func)
            return

        if opcode == OpCode.REPORT_SPEED:
            # vx, vy, vz (mm/s → m/s)
            self._vx = struct.unpack("<h", data[0:2])[0] / 1000.0
            self._vy = struct.unpack("<h", data[2:4])[0] / 1000.0
            self._vz = struct.unpack("<h", data[4:6])[0] / 1000.0
            self._battery_raw = data[6]

        elif opcode == OpCode.REPORT_MPU_RAW:
            gyro_ratio = 1.0 / 3754.9
            accel_ratio = 1.0 / 1671.84
            mag_ratio = 1.0

            self._gx = struct.unpack("<h", data[0:2])[0] * gyro_ratio
            self._gy = struct.unpack("<h", data[2:4])[0] * -gyro_ratio
            self._gz = struct.unpack("<h", data[4:6])[0] * -gyro_ratio

            self._ax = struct.unpack("<h", data[6:8])[0] * accel_ratio
            self._ay = struct.unpack("<h", data[8:10])[0] * accel_ratio
            self._az = struct.unpack("<h", data[10:12])[0] * accel_ratio

            self._mx = struct.unpack("<h", data[12:14])[0] * mag_ratio
            self._my = struct.unpack("<h", data[14:16])[0] * mag_ratio
            self._mz = struct.unpack("<h", data[16:18])[0] * mag_ratio

        elif opcode == OpCode.REPORT_ICM_RAW:
            ratio = 1.0 / 1000.0
            self._gx = struct.unpack("<h", data[0:2])[0] * ratio
            self._gy = struct.unpack("<h", data[2:4])[0] * ratio
            self._gz = struct.unpack("<h", data[4:6])[0] * ratio

            self._ax = struct.unpack("<h", data[6:8])[0] * ratio
            self._ay = struct.unpack("<h", data[8:10])[0] * ratio
            self._az = struct.unpack("<h", data[10:12])[0] * ratio

            self._mx = struct.unpack("<h", data[12:14])[0] * ratio
            self._my = struct.unpack("<h", data[14:16])[0] * ratio
            self._mz = struct.unpack("<h", data[16:18])[0] * ratio

        elif opcode == OpCode.REPORT_IMU_ATT:
            self._roll  = struct.unpack("<h", data[0:2])[0] / 10000.0
            self._pitch = struct.unpack("<h", data[2:4])[0] / 10000.0
            self._yaw   = struct.unpack("<h", data[4:6])[0] / 10000.0

        elif opcode == OpCode.REPORT_ENCODER:
            self._enc_m1 = struct.unpack("<i", data[0:4])[0]
            self._enc_m2 = struct.unpack("<i", data[4:8])[0]
            self._enc_m3 = struct.unpack("<i", data[8:12])[0]
            self._enc_m4 = struct.unpack("<i", data[12:16])[0]

        elif opcode == OpCode.VERSION:
            self._version_major = data[0]
            self._version_minor = data[1]
            self._version = self._version_major + self._version_minor / 10.0
            if self._debug:
                print("FW version:", self._version)

        elif opcode == OpCode.SET_MOTOR_PID:
            self._pid_index = data[0]
            self._kp_raw = struct.unpack("<h", data[1:3])[0]
            self._ki_raw = struct.unpack("<h", data[3:5])[0]
            self._kd_raw = struct.unpack("<h", data[5:7])[0]

        elif opcode == OpCode.AKM_DEF_ANGLE:
            _id = data[0]
            self._akm_default_angle = data[1]
            self._akm_angle_ready = True

        elif opcode == OpCode.SET_CAR_TYPE:
            self._car_type_read = data[0]

        else:
            # 이 예제에선 arm, servo 등은 생략 (필요하면 확장)
            if self._debug:
                print("Unhandled report:", opcode, list(data))

    # ---------------------- Request/Response ----------------------

    def _request_data(self, opcode: OpCode, param: int = 0) -> None:
        """MCU에 특정 데이터를 요청하는 프레임 전송."""
        b = self._build_frame(OpCode.REQUEST_DATA)
        b.add_u8(int(opcode) & 0xFF, param & 0xFF)
        self._send(b.build())

    # ---------------------- 기본 제어 API ----------------------

    def set_auto_report(self, enabled: bool, persist: bool = False) -> None:
        """MCU의 자동 보고 기능 on/off."""
        state = 1 if enabled else 0
        flag = 0x5F if persist else 0
        b = self._build_frame(OpCode.AUTO_REPORT)
        b.add_u8(state, flag)
        self._send(b.build())

    def beep(self, duration_ms: int) -> None:
        """지정한 시간(duration_ms) 동안 부저 ON (0=OFF, 1=계속)."""
        if duration_ms < 0:
            raise ValueError("duration_ms must be >= 0")
        b = self._build_frame(OpCode.BEEP)
        b.add_i16(duration_ms)
        self._send(b.build())

    # ---------------------- 모터 관련 ----------------------

    @staticmethod
    def _limit_motor(value: int) -> int:
        if value == 127:
            return 127
        if value > 100:
            return 100
        if value < -100:
            return -100
        return int(value)

    def set_wheel_pwm(self, m1: int, m2: int, m3: int, m4: int) -> None:
        """각 바퀴 PWM(-100~100) 직접 지정 (양수=전진)."""
        b = self._build_frame(OpCode.MOTOR_PWM)
        b.add_i8(
            self._limit_motor(self.MOTOR_POLARITY * m1),
            self._limit_motor(self.MOTOR_POLARITY * m2),
            self._limit_motor(self.MOTOR_POLARITY * m3),
            self._limit_motor(self.MOTOR_POLARITY * m4),
        )
        self._send(b.build())

    def command_direction(self, state: int, speed: int, use_adjust: bool = False) -> None:
        """
        단순 방향 제어:
        state: 0=STOP, 1=전진, 2=후진, 3=좌, 4=우, 5=좌회전, 6=우회전, 7=주차
        speed: -100~100
        """
        car_type_flag = self._car_type
        if use_adjust:
            car_type_flag |= self._CAR_ADJUST_FLAG

        speed_bytes = struct.pack("<h", int(speed))
        b = self._build_frame(OpCode.CAR_RUN)
        b.add_u8(car_type_flag, state & 0xFF)
        b.payload.extend(speed_bytes)
        self._send(b.build())

    def set_motion(self, vx: float, vy: float, wz: float) -> None:
        """
        기구학 기반 속도 명령:
        vx, vy [m/s], wz [rad/s] → 내부에서 1000배 스케일로 전송.
        """
        vx_i = int(vx * 1000)
        vy_i = int(vy * 1000)
        wz_i = int(wz * 1000)
        b = self._build_frame(OpCode.MOTION)
        b.add_u8(self._car_type)
        b.add_i16(vx_i, vy_i, wz_i)
        self._send(b.build())

    # ---------------------- PID ----------------------

    def set_motion_pid(self, kp: float, ki: float, kd: float, persist: bool = False) -> None:
        """속도 PID 파라미터 설정 (0~10.0 범위 권장)."""
        if not (0 <= kp <= 10 and 0 <= ki <= 10 and 0 <= kd <= 10):
            raise ValueError("kp/ki/kd must be in [0, 10.0]")

        state = 0x5F if persist else 0
        b = self._build_frame(OpCode.SET_MOTOR_PID)
        b.add_i16(int(kp * 1000), int(ki * 1000), int(kd * 1000))
        b.add_u8(state)
        self._send(b.build())
        if persist:
            time.sleep(0.1)

    def get_motion_pid(self) -> Tuple[float, float, float]:
        """MCU에 저장된 속도 PID 값 읽기."""
        self._kp_raw = self._ki_raw = self._kd_raw = 0
        self._pid_index = 0
        self._request_data(OpCode.SET_MOTOR_PID, 1)

        for _ in range(20):
            if self._pid_index > 0:
                return (
                    self._kp_raw / 1000.0,
                    self._ki_raw / 1000.0,
                    self._kd_raw / 1000.0,
                )
            time.sleep(0.001)
        return -1.0, -1.0, -1.0

    # ---------------------- car type / flash / state ----------------------

    def set_car_type(self, car_type: int) -> None:
        """하위 보드에 car type 저장."""
        self._car_type = car_type & 0xFF
        b = self._build_frame(OpCode.SET_CAR_TYPE)
        b.add_u8(self._car_type, 0x5F)  # 0x5F: flash 저장 플래그
        self._send(b.build())
        time.sleep(0.1)

    def get_car_type_from_mcu(self) -> int:
        """MCU에 저장된 car type 읽기."""
        self._car_type_read = 0
        self._request_data(OpCode.SET_CAR_TYPE)
        for _ in range(20):
            if self._car_type_read != 0:
                tmp = self._car_type_read
                self._car_type_read = 0
                return tmp
            time.sleep(0.001)
        return -1

    def reset_flash(self) -> None:
        """MCU flash에 저장된 값 초기화(공장값)."""
        b = self._build_frame(OpCode.RESET_FLASH)
        b.add_u8(0x5F)
        self._send(b.build())
        time.sleep(0.1)

    def reset_runtime_state(self) -> None:
        """차량 상태 초기화: 정지, LED/부저 OFF."""
        b = self._build_frame(OpCode.RESET_STATE)
        b.add_u8(0x5F)
        self._send(b.build())

    # ---------------------- 버전 ----------------------

    def get_firmware_version(self) -> float:
        """MCU 펌웨어 버전(Vx.y) 반환."""
        if self._version_major == 0:
            self._request_data(OpCode.VERSION)
            for _ in range(20):
                if self._version_major != 0:
                    return self._version
                time.sleep(0.001)
        return self._version

    # ---------------------- 센서 읽기 API ----------------------

    def get_accel(self) -> Tuple[float, float, float]:
        """가속도 (ax, ay, az) [m/s^2]."""
        return self._ax, self._ay, self._az

    def get_gyro(self) -> Tuple[float, float, float]:
        """각속도 (gx, gy, gz) [rad/s]."""
        return self._gx, self._gy, self._gz

    def get_mag(self) -> Tuple[float, float, float]:
        """자기장 (mx, my, mz) [임의 단위]."""
        return self._mx, self._my, self._mz

    def get_attitude(self, in_degrees: bool = True) -> Tuple[float, float, float]:
        """roll, pitch, yaw 반환 (기본: 도 단위)."""
        if in_degrees:
            r2d = 57.2957795
            return self._roll * r2d, self._pitch * r2d, self._yaw * r2d
        return self._roll, self._pitch, self._yaw

    def get_motion(self) -> Tuple[float, float, float]:
        """vx, vy, wz [m/s, m/s, rad/s]."""
        return self._vx, self._vy, self._vz

    def get_battery_voltage(self) -> float:
        """배터리 전압 [V]."""
        return self._battery_raw / 10.0

    def get_encoders(self) -> Tuple[int, int, int, int]:
        """4개 바퀴 엔코더 카운트."""
        return self._enc_m1, self._enc_m2, self._enc_m3, self._enc_m4

    # ---------------------- Ackermann 일부 예시 ----------------------

    def set_akm_default_angle(self, angle: int, persist: bool = False) -> None:
        """Ackermann 차량 기본 조향 각도 설정 (예: 60~120)."""
        if not (60 <= angle <= 120):
            return
        state = 0x5F if persist else 0
        b = self._build_frame(OpCode.AKM_DEF_ANGLE)
        b.add_u8(self._akm_servo_id, angle, state)
        self._send(b.build())
        if persist:
            time.sleep(0.1)

    def get_akm_default_angle(self) -> int:
        """MCU에서 Ackermann 기본 각도 읽기."""
        if not self._akm_angle_ready:
            self._request_data(OpCode.AKM_DEF_ANGLE, self._akm_servo_id)
            cnt = 0
            while not self._akm_angle_ready and cnt < 100:
                time.sleep(0.01)
                cnt += 1
            if not self._akm_angle_ready:
                return -1
        return self._akm_default_angle

    def set_akm_steering(self, angle_delta: int, control_car_speed: bool = False) -> None:
        """
        Ackermann 차량 조향 각도 설정 (center 기준 좌/우 ±45).
        control_car_speed=True면 모터 속도도 같이 조정.
        """
        if not (-45 <= angle_delta <= 45):
            return
        sid = self._akm_servo_id | (0x80 if control_car_speed else 0x00)
        b = self._build_frame(OpCode.AKM_STEER_ANGLE)
        b.add_u8(sid, angle_delta & 0xFF)
        self._send(b.build())

    # ---------------------- 종료 처리 ----------------------

    def close(self) -> None:
        """백그라운드 리더를 멈추고 시리얼 포트 닫기."""
        # 먼저 rx_loop 에 정지 신호(state=2) → join 으로 스레드가 read 를 끝내고
        # 빠져나가길 기다린 뒤 시리얼을 닫는다(닫힌 포트 read race 방지).
        self._uart_thread_state = 2
        t = self._rx_thread
        if t is not None and t.is_alive():
            t.join(timeout=1.0)
        if self._ser and self._ser.is_open:
            self._ser.close()
            print("TriboBase: serial closed")

    def __del__(self):
        try:
            self.close()
        except Exception:
            pass


# ============================ 예제 사용 ============================

if __name__ == "__main__":
    bot = TriboBase(port="/dev/ttyUSB0", car_type=TriboBase.CARTYPE_X3, debug=True)

    bot.start_background_reader()
    time.sleep(0.1)

    # 자동 리포트 켜기
    bot.set_auto_report(True, persist=False)

    # 비프 테스트
    bot.beep(50)

    # 버전 확인
    print("FW version:", bot.get_firmware_version())

    # 모터 & IMU 테스트 루프
    try:
        bot.set_motion(0.2, 0.0, 0.0)
        for _ in range(50):
            ax, ay, az = bot.get_accel()
            gx, gy, gz = bot.get_gyro()
            mx, my, mz = bot.get_mag()
            print("ACC:", ax, ay, az, "| GYR:", gx, gy, gz, "| MAG:", mx, my, mz)
            time.sleep(0.1)
        bot.set_motion(0.0, 0.0, 0.0)
    except KeyboardInterrupt:
        bot.set_motion(0.0, 0.0, 0.0)
        bot.close()

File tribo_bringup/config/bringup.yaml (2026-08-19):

# tribo_bringup (hardware + teleop interface)
tribo_bringup:
  ros__parameters:
    # Serial — port is set by bringup.launch.py (resolved udev /dev/tribo_base, or
    # by-id fallback). Left unset here so the launch value is authoritative; for a
    # standalone `ros2 run`, the node default (base by-id) applies.
    baudrate: 115200
    car_type: 1

    # Motion interface
    use_motion_mode: false
    # 2026-07-29 메카넘(82mm) 실측 후 0.50 -> 0.85 (기체 76c02a, pwm_min 20 기준).
    # ⚠️ 이 값은 "최고속"이 아니라 정규화 분모다(duty = |v_wheel| / max_lin_vel).
    #    실측 최고속은 듀티 100%에서 0.443 m/s 로, 오히려 0.50 보다 낮다.
    #    그런데 응답이 오목(저듀티 가파름/고듀티 완만)해서 천장값을 그대로 넣으면
    #    중속 대역이 더 어긋난다 — 분모를 줄이면 듀티가 올라 더 빨라지기 때문(아래 주석).
    # 실측 v_steady: duty 20%->0.216, 50%->0.322, 80%->0.412, 100%->0.443 m/s.
    # 0.85 는 Nav2 동작대역(0.2~0.3)에서 명령=실제가 되도록 역산한 값이다:
    #    0.20->0.23, 0.25->0.25, 0.30->0.27 (오차 10% 이내).
    # ⚠️ 대신 0.35 이상은 물리적으로 못 낸다 → nav2_params 의 속도 상한을 그에 맞출 것.
    # ⚠️ 오프셋이 있는 응답이라 단일 배율로는 전 대역을 맞출 수 없다. 정확히 맞추려면
    #    회전의 rot_lin 과 같은 역아핀 선형화가 직진에도 필요하다(미구현).
    max_lin_vel: 0.85
    max_ang_vel: 2.00
    turn_scale: 1.00

    # Differential approximation
    # (track_width comes from robot_geom.yaml)

    # cmd_vel safety
    vx_deadzone: 0.02
    wz_deadzone: 0.05
    cmd_timeout: 0.50

    # cmd_vel direction (verified on robot 2026-06-08, motors m1~m4 correctly wired):
    #   invert_cmd_vel=true        -> teleop forward = robot forward
    #   invert_cmd_vel_angular=true -> teleop left = robot left
    invert_cmd_vel: true
    invert_cmd_vel_angular: true

    # Per-motor calibration
    gain_m1: 1.000   # FL
    gain_m2: 0.977   # RL
    gain_m3: 0.78  # RR
    gain_m4: 0.73   # FR

    # Reverse-direction (backward) extra factors
    gain_left_rev_factor: 1.00
    gain_right_rev_factor: 1.00

    # Per-motor direction invert (use ONLY if a wheel spins backward for +cmd_vel)
    invert_m1: false
    invert_m2: false
    invert_m3: false
    invert_m4: false

    # Minimum PWM to overcome static friction (0~100)
    # 2026-07-29 메카넘(82mm) 교체 후 35.0 -> 20.0.
    # 메카넘은 구름저항이 낮아 35% 바닥이 이미 0.28 m/s 를 냈다. 0이 아닌 어떤 저속을
    # 명령해도 전부 이 바닥으로 클램프돼 최저 달성속도가 0.28 이 되고, Nav2 가 요구하는
    # 0.2~0.25 는 물리적으로 추종 불가능했다(명령 0.15에 실제 0.28 이 나온 원인).
    # 20 으로 낮춰 최저속을 0.216 m/s 로 내렸고, 이 값에서도 스톨 없이 직진했다
    # (yaw 드리프트 -0.15°). 더 낮추면 정지마찰을 못 이겨 스톨할 수 있어 미탐색.
    pwm_min_percent: 20.0

    # Maximum PWM duty (0~100) — caps peak motor current.
    # ⚠️ Do NOT try to "slow the robot down" by lowering max_lin_vel. Normalization is
    #    a = |v_wheel| / max_lin_vel, so shrinking the denominator RAISES the duty.
    #    This ceiling is the only knob that actually reduces motor output/current.
    # In-place rotation is the worst case: all 4 wheels fight scrub friction at once.
    # If the supply (battery/adapter) cannot take that peak, over-current protection
    # trips and the robot resets mid-drive.
    # ⚠️ PER-ROBOT: a unit with a weak/binding motor needs a high rotate_pwm_min to spin
    #    at all, which pushes current up — cap it here via config/motor_calib.yaml.
    pwm_max_percent: 100.0

    # Rotation-only PWM boost (skid-steer lateral scrub friction stalls in-place turns).
    # Applied ONLY for IN-PLACE turns: |wz| >= rotate_wz_threshold AND |vx| <= rotate_pwm_vx_max.
    # 순수 직진은 물론이고 곡선 주행에도 적용되지 않는다. Tuned on-floor 2026-06-15.
    rotate_pwm_min: 45.0          # min PWM duty (%) for wheels contributing to rotation
    rotate_wz_threshold: 0.10     # rad/s; |wz| above this is treated as a turn
    # 2026-07-29 추가. 이게 없으면 곡선 주행(vx>0, wz>0)에도 회전 바닥이 걸려 안쪽 바퀴
    # 듀티가 바닥까지 올라가고 좌우 차이가 붕괴해 곡률이 사라진다.
    # 예: vx=0.25, wz=0.2 → 좌 21.1% / 우 37.8% 인데 바닥 35% 를 먹이면 35 / 37.8 이
    # 되어 차이가 16.7%p → 2.8%p. 곡률의 83% 가 날아가 사실상 직진이 된다. 그 결과
    # 로봇이 낼 수 있는 동작이 "직진"과 "제자리 회전" 둘뿐이었다.
    # 굴러가는 중에는 정지마찰을 넘을 필요가 없으므로 바닥 자체가 불필요하다.
    rotate_pwm_vx_max: 0.05       # m/s; |vx| 가 이 이하일 때만 회전 바닥 적용(=제자리 회전)

    # In-place rotation linearization (inverse-affine).
    # Open-loop PWM response is affine, not proportional:
    #   actual_wz ~= rot_lin_offset + rot_lin_slope * internal_wz
    # The offset is the floor (rotate_pwm_min) imposing a MINIMUM spin rate, which is why
    # turn_scale (a pure gain) cannot fix tracking. We invert the fit instead.
    # ⚠️ PER-ROBOT: these were measured on tribo v2. Re-measure per robot and override in
    #    config/motor_calib.yaml (gitignored), same as gain_m*.
    # Measure: sweep `ros2 run tribo_odom rotation_calib -p angular_speed:=<w>` and fit
    #    actual vs commanded. Battery must be >11V or the fit is garbage.
    rot_lin_enable: true
    rot_lin_offset: 0.186         # rad/s — minimum achievable spin (PWM floor)
    rot_lin_slope: 0.216
    rot_lin_max_wz: 0.55          # rad/s — measured ceiling is ~0.6; stay under it
    rot_lin_vx_max: 0.02          # only linearize when |vx| <= this (in-place spin)
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

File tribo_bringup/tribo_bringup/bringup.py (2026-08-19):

#!/usr/bin/env python3
# -*- coding: utf-8 -*-

"""
tribo_bringup_tribolib

TriboBase (tribolib)를 사용해서 Rosmaster 보드를 제어하는 bringup 노드.

- 하위: tribolib.TriboBase (바이너리 시리얼 프로토콜)
- 상위: /cmd_vel 구독 + 엔코더/휠속도 퍼브리시

주요 기능
1) cmd_vel → 좌/우 속도로 변환 → per-motor gain / invert 적용
2) PWM 모드: TriboBase.set_wheel_pwm(-100~100) 사용
3) auto_report를 통해 들어오는 엔코더 값을 주기적으로 읽어 퍼블리시
4) cmd_timeout 초 동안 명령이 없으면 자동 정지

Motor mapping (Rosmaster 기준)
  m1=FL, m2=RL, m3=RR, m4=FR
"""

import math
import time

import rclpy
from rclpy.node import Node
from geometry_msgs.msg import Twist
from std_msgs.msg import Int32MultiArray, Float32MultiArray
from sensor_msgs.msg import BatteryState

from .tribolib import TriboBase


class TriboBringupTribolib(Node):
    def __init__(self):
        super().__init__("tribo_bringup")

        # ---- Serial / hardware params ----
        self.declare_parameter("port", "/dev/serial/by-id/usb-1a86_USB_Serial-if00-port0")
        self.declare_parameter("baudrate", 115200)
        self.declare_parameter("car_type", TriboBase.CARTYPE_X3)
        self.declare_parameter("debug_hw", False)

        # ---- Command / motion params ----
        self.declare_parameter("use_motion_mode", False)   # True면 set_motion(vx,0,wz) 사용
        self.declare_parameter("max_lin_vel", 0.5)         # m/s
        self.declare_parameter("max_ang_vel", 6.0)         # rad/s
        self.declare_parameter("turn_scale", 0.85)          # 회전만 키울 때
        self.declare_parameter("track_width", 0.12)        # m (좌우 바퀴 간 거리)
        self.declare_parameter("invert_cmd_vel", True)
        self.declare_parameter("invert_cmd_vel_angular", False)

        self.declare_parameter("vx_deadzone", 0.02)
        self.declare_parameter("wz_deadzone", 0.05)
        self.declare_parameter("cmd_timeout", 0.4)

        # ---- PWM 모드용 calib gain (정규화 기준 -1~1) ----
        self.declare_parameter("gain_m1", 0.98)
        self.declare_parameter("gain_m2", 0.98)
        self.declare_parameter("gain_m3", 1.0)
        self.declare_parameter("gain_m4", 1.0)
        # ---- 방향별(후진) 보정 계수 ----
        self.declare_parameter("gain_left_rev_factor", 1.0)   # left_norm < 0 일 때만 추가 곱
        self.declare_parameter("gain_right_rev_factor", 1.0)  # right_norm < 0 일 때만 추가 곱

        self.declare_parameter("invert_m1", False)
        self.declare_parameter("invert_m2", False)
        self.declare_parameter("invert_m3", False)
        self.declare_parameter("invert_m4", False)

        # Rosmaster PWM은 -100~100이지만,
        # 너무 작을 때는 모터가 안 도는 deadzone이 있으므로
        # |x|>0 일 때 최소 듀티(%)를 설정
        self.declare_parameter("pwm_min_percent", 20.0)    # 0~100

        # ---- PWM 천장 (전류 상한) ----
        # PWM 은 pwm_min ~ pwm_max 구간으로 매핑된다. 기본 100 = 종전과 동일.
        # ⚠️ max_lin_vel 을 낮춰 "속도를 줄이는" 것은 역효과다. 정규화가
        #    a = |v_바퀴| / max_lin_vel 이라 분모를 줄이면 a 가 커져 PWM 이 오른다.
        #    모터 출력·전류를 실제로 줄이려면 이 천장을 내려야 한다.
        # 제자리 회전은 4바퀴가 동시에 스크럽과 싸워 전류 피크가 가장 크다.
        # 전원(배터리/어댑터)이 그 피크를 못 버티면 과전류 보호가 트립되어
        # 로봇이 리셋된다 → 기체·전원별로 낮춰 잡을 것 (motor_calib.yaml).
        self.declare_parameter("pwm_max_percent", 100.0)   # 0~100

        # ---- 회전 전용 PWM 부스트 ----
        # 4륜 스키드-스티어는 제자리 회전 시 횡방향 타이어 스크럽 마찰로 stall한다.
        # 회전 성분(wz)이 유의미할 때만 그 회전에 기여하는 바퀴의 PWM 바닥을
        # rotate_pwm_min 으로 올려서 stall을 넘긴다.
        # 순수 직진(|wz|이 임계 미만)에는 절대 적용되지 않으며 기존 pwm_min_percent만 쓴다.
        self.declare_parameter("rotate_pwm_min", 45.0)         # 회전 시 적용 최소 듀티(%) (>= pwm_min_percent 권장)
        self.declare_parameter("rotate_wz_threshold", 0.10)    # |wz(turn_scale 적용 후)|가 이 값 이상이면 회전으로 간주 [rad/s]
        # ⚠️ 이 바닥은 "제자리 회전"에서만 적용해야 한다. |wz| 만으로 판정하면 곡선 주행
        #    (vx>0 이면서 wz>0)에도 걸리는데, 그러면 안쪽 바퀴 듀티가 바닥까지 끌어올려져
        #    좌우 차이가 붕괴하고 곡률이 사라진다. 예: vx=0.25, wz=0.2, track 0.71,
        #    max_lin_vel 0.85 → 좌 21.1% / 우 37.8% 인데 바닥 35% 를 먹이면 35 / 37.8 이
        #    되어 차이가 16.7%p → 2.8%p. 곡률의 83% 가 날아가 사실상 직진이 된다.
        #    이미 굴러가는 중이면 정지마찰을 넘을 필요가 없으므로 바닥도 필요 없다.
        #    rot_lin_vx_max 와 같은 방식으로 |vx| 상한을 함께 본다.
        self.declare_parameter("rotate_pwm_vx_max", 0.05)      # |vx| 가 이 이하일 때만 회전 바닥 적용 [m/s]

        # ---- 제자리 회전 선형화 (역아핀 보정) ----
        # 개루프 PWM 에서 실측한 제자리 회전 응답은 비례가 아니라 아핀이다:
        #     실제_wz ≈ rot_lin_offset + rot_lin_slope * 내부_wz      (내부_wz > 0 일 때)
        # offset 은 PWM 바닥(rotate_pwm_min)이 만드는 최소 회전속도이고, 이것 때문에
        # turn_scale 같은 순수 게인으로는 명령을 맞출 수 없다(필요 배율이 명령마다 달라짐).
        # 그래서 목표 wz 를 역으로 풀어 내부 wz 로 바꿔 보낸다:
        #     내부_wz = (목표_wz - offset) / slope
        # 계수는 기체마다 다르다 → motor_calib.yaml 처럼 로봇별로 덮어쓸 것.
        # 측정: 여러 angular_speed 로 제자리 회전시키며 명령 wz 대비 실제 wz 를 잰다.
        #       (실제 wz 는 라이다 스캔 상관으로 측정 — IMU 기반 rotation_calib 은 보드
        #        자이로가 지속 회전에서 죽어 2026-07-15 제거됨.)
        # 주의: 계수는 *제자리* 회전(vx≈0)에서 잰 값이다. 전진 중 선회는 스크럽이 달라
        #       같은 식이 성립하지 않으므로, |vx| 가 작을 때만 적용한다.
        self.declare_parameter("rot_lin_enable", True)
        self.declare_parameter("rot_lin_offset", 0.186)   # rad/s (tribo v2 실측)
        self.declare_parameter("rot_lin_slope", 0.216)    # (tribo v2 실측)
        self.declare_parameter("rot_lin_max_wz", 0.55)    # 실측 물리 천장(~0.6)보다 여유 있게 아래
        self.declare_parameter("rot_lin_vx_max", 0.02)    # |vx| 가 이 이하일 때만 = 제자리 회전으로 간주
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

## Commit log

2026-01-26 modify package name
    [gazebo_control.xacro, inertial_macros.xacro, lidar.xacro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]
2026-05-28 refactor: re-enable cmd_vel watchdog, add .gitignore, untrack pyc
    - bringup.py: 주석 처리됐던 watchdog 타이머 재활성화
    (cmd_vel이 cmd_timeout초 동안 없으면 자동 정지 - 안전 기능)
    - bringup.py: docstring 오타 수정 (좌/우, 휠속도, TriboBase)
    - 추적되던 __pycache__/*.pyc 4개 제거 (고아 .pyc 포함)
    - .gitignore 추가 (__pycache__, build/install/log 등)
    [bringup.py]
2026-05-28 docs: rewrite README as full setup guide for new robot (Jazzy)
    - humble -> jazzy 의존성 갱신
    - 서브모듈 포함 클론, dialout 권한, 라이다 by-id 주의사항 추가
    - ROS_DOMAIN_ID 고정, 실행/SLAM/Nav2/Gazebo, 문제 해결 표
2026-05-28 feat(bringup): publish board IMU as sensor_msgs/Imu on /imu/data
    - bringup.py: 보드 9축 IMU(자세/각속도/가속도)를 /imu/data로 퍼블리시
    - imu_rate(기본 50Hz) 타이머, base_link 프레임, ekf.yaml imu0와 연동
    - invert_imu_yaw 파라미터로 yaw/gz 부호 보정 가능
    - 2D 융합용 대각 공분산(yaw/yaw-rate만 신뢰) 설정
    - bringup.yaml: IMU 파라미터 추가
    - package.xml: 누락된 런타임 의존성 선언(rclpy/geometry_msgs/std_msgs/sensor_msgs/pyserial)
2026-05-28 calib: separate physical vs effective track_width (odom yaw)
    - robot_geom.yaml: track_width 0.40 -> 0.52 (physical, measured) for bringup kinematics
    - odom.yaml / bringup.launch.py: odom uses effective track 0.735 (slip-calibrated)
    -> in-place rotation slips; odom yaw was 1.84x over (100deg vs ~55deg actual/IMU)
    -> after fix: odom yaw matches IMU within 0.1% over 31/70 deg test rotations
    - straight-drive calib confirmed wheel_radius/ticks accurate (57.7 odom vs ~57.6 real)
    - odom.yaml invert_rotation false->true (match working bringup.launch.py, sign verified)
    [robot_geom.yaml]
2026-05-28 feat: publish board battery + wire up EKF (encoder odom + IMU fusion)
    Battery
    - bringup.py: publish sensor_msgs/BatteryState on /battery (1Hz),
    percentage from full/empty params, low-voltage warning log
    - bringup.yaml: 3S Li defaults (full 12.6 / empty 9.0 / warn 10.5 V)
    verified on robot: 11.30 V -> 64%
    EKF (robot_localization) wiring
    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
2026-05-28 docs: add SLAM mapping + Nav2 run guide to README
    Replace the two-line nav stub with full step-by-step sections covering
    map building (slam_toolbox + map_saver) and Nav2 launch flow with the
    bringup_launch.xml + RViz initial-pose workflow. Notes the two common
    pitfalls (navigation_launch.xml alone has no map_server/amcl; map:= path
    must be resolved on the machine running launch).
2026-05-28 feat: invert lidar URDF mount + auto-fullscreen RViz on robot LCD
    - URDF: laser_link_fixed_joint yaw set to pi to compensate for the
    upside-down LiDAR mount so /scan frame aligns with the environment.
    - tribo_navigation/bringup_launch.xml: add use_rviz arg (default true)
    and an RViz node that runs through launch_rviz_on_lcd.sh, which
    resolves DISPLAY/XAUTHORITY on the robots GNOME Wayland session and
    starts rviz2 --fullscreen on the connected LCD.
    - scripts/launch_rviz_on_lcd.sh: new wrapper for runtime env assembly.
    - setup.py: install scripts/*.sh into lib/<pkg>/ so the launch can
    locate the wrapper.
    - README 6-4: LCD auto-display notes + PC simultaneous view tip.
    Co-Authored-By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
    [robot_core.xacro]
2026-05-28 feat: switch to RPP controller + work around board IMU yaw freeze
    Controller (nav2_params): replace MPPIController (2000 trajectories, 8
    critics, allows reversing) with RegulatedPurePursuitController for
    predictable rotate-to-heading + straight-line motion. allow_reversing
    is disabled.
    EKF (ekf.yaml + bringup.py): board firmware never updates the IMU yaw
    payload (orientation z/w freeze observed; gz/roll/pitch update fine).
    Stop trusting orientation in EKF (imu0_config orientation rows all
    false), keep only vyaw=gz. bringup forces orientation.yaw to 0 and
    inflates orientation_covariance to 1e6 so any other consumer ignores
    the frozen value.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
    [bringup.py]
2026-05-29 feat(sim): 2단 트롤리 외형 + IMU/Depth카메라 + SLAM 실습 월드 + odom 보정
    - robot_core: 박스 1개 → 2단 트롤리 외형(구동 베이스 + 모터4 + 프로파일
    프레임 + 선반 플레이트 + LCD). 치수 파라미터화, 무게중심 하향.
    바퀴를 차체 바깥으로 돌출시키고 모터를 베이스 하단에 배치.
    - imu.xacro / depth_camera.xacro 추가 (gz imu, rgbd_camera 센서)
    - bridge: 카메라 토픽 4종 + joint_states(바퀴 TF) 추가
    - world: 단순 방 → 8x6m 실내(방3 + 복도 + 문3 + 장애물5), self-contained
    ground_plane 인라인화(외부 모델 의존 제거)
    - launch_sim: gz 서버 미기동(-g) 수정, 스폰 -z 0.05(바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
    [depth_camera.xacro, gazebo_control.xacro, imu.xacro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]
2026-06-02 docs: add headless Raspberry Pi SSH setup section to README
    새 라즈베리파이 로봇 초기 세팅 시 SSH 접속이 필요하므로, 설치 단계 앞에
    원격 접속(SSH) 설정 섹션 추가. ping/nc 증상 진단, openssh-server 설치·활성화,
    접속 확인 절차 포함. 이후 장 번호(4~9) 재정렬 및 문제 해결 표에 SSH 행 추가.
2026-06-02 docs: add SSH key registration (ssh-copy-id) step to README
    비밀번호 없는 접속을 위해 ssh-copy-id로 PC 공개키를 로봇에 등록하는
    3-4 절 추가. 키 생성/등록/확인 절차와 alias 운용 팁 포함.
2026-06-02 docs: expand dialout group setup with re-login and verify steps
    5-1절에 could not open port 실패 원인, 재로그인(또는 재부팅) 필수,
    groups로 dialout 확인하는 검증 단계, ttyUSB 권한 설명 추가.
2026-06-08 fix(bringup): cmd_vel 전후/좌우 방향 보정 (invert_cmd_vel, invert_cmd_vel_angular)
    bringup.yaml에 cmd_vel 방향 보정 추가.
    - invert_cmd_vel: true
    - invert_cmd_vel_angular: true
    모터 m1~m4 올바른 배선 상태에서 실로봇 검증 통과 (2026-06-08):
    teleop 전진=로봇 전진, 좌회전=로봇 좌회전.
    [bringup.yaml]
2026-06-11 feat(bringup): 시리얼 포트 자동해석·odom 부호 보정·재실행 안전화
    - 라이다/보드 시리얼 포트 충돌 해결: bringup.launch.py가 sllidar 런치에 serial_port를 by-id로 전달(기존 frame_id만 전달→라이다가 보드 포트를 열어 충돌). sensors.launch.py 동일 수정.
    - odom 전/후 부호 보정: invert_cmd_vel 도입 후 보드 엔코더가 전진 시 음수 tick → odom invert_translation=true (실로봇 전진펄스 dx +0.29m 검증).
    - USB 포트 변동 강건화: udev 규칙(99-tribo-serial.rules)로 /dev/tribo_base·/dev/tribo_lidar 고정 + bringup.launch.py가 udev심볼릭→by-id 폴백 자동해석. bringup.yaml port 제거(launch 단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
    [bringup.yaml]
2026-06-11 feat(odom): 회전 슬립 보정 — IMU 자이로 yaw 융합 + rotation_calib 도구
    - bringup.yaml: invert_imu_yaw=true (보드 gz 부호가 엔코더와 반대, 실측 확인)
    - ekf.yaml: 회전(yaw/vyaw)을 휠 odom에서 끄고 IMU vyaw로 추정. 4륜 스키드가
    제자리/급회전 시 바퀴가 헛돌아 휠 odom yaw가 과대적분 → /odom 회전이 실제보다
    빨랐음. EKF/IMU=0.969로 /odom 회전이 실제와 일치 검증.
    - bringup.launch.py: 유효 track_width 0.735 → 0.873 (rotation_calib 측정값;
    /odom_raw 및 use_ekf=false 레거시 경로용. EKF는 IMU 회전이라 영향 없음)
    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
2026-06-11 docs(perf): Pi5 Nav2 성능 — CPU governor performance + EKF 30Hz
    - README 5-4: CPU 거버너를 performance로 설정. Pi5 기본 ondemand면 Nav2
    12노드 버스트 시작 시 클럭(2.4GHz)이 못 따라와 controller_server가 느려
    lifecycle_manager가 'get_state service is not available'로 nav 전체 abort,
    ekf_node도 'Failed to meet update rate' 다발. 즉시적용 + systemd 영구화.
    - tribo_bringup/system/cpu-performance.service: 거버너 영구화 systemd 유닛(신규)
    - ekf.yaml: EKF frequency 50 -> 30Hz (Pi5 Nav2 동시구동 부하 경감; 단독 30Hz
    안정·/odom 30Hz 검증)
    - README 9: nav abort(거버너)·Ctrl-C 잔여노드(pkill -f 'ros-args')·egg-info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
2026-06-18 docs(bringup): CPU performance 거버너 systemd 설치 절차 실로봇 검증분 보강
    - 유닛 복사 후 daemon-reload 단계 추가
    - 검증 명령을 systemctl status 대신 is-enabled/is-active로 명확화
    - 재부팅 후 4코어 전부 performance인지 scaling_governor 확인 라인 추가
2026-07-07 docs(readme): 같은 IP 새 로봇 접속 시 호스트키 변경 경고 대응 절차 추가
    - 3-5 신규 소절: REMOTE HOST IDENTIFICATION HAS CHANGED 경고 시
    ssh-keygen -R 로 옛 호스트키 제거 후 재접속
    - 9장 문제 해결 표에 Host key verification failed 행 추가
    - Connection refused 행 참조 (3장)->(3-2) 정밀화
2026-07-07 docs(readme): 설치 절차에 PC/로봇 수행 대상 명시
    - 4장 설치에 PC/로봇 양쪽 수행 안내 배너 및 대상 요약 표 추가
    - 4-1/4-2/4-3/4-4 소절 제목에 대상 태그 명시, gazebo 시뮬 블록 PC 전용, 5장 로봇 전용 표기
    - 4-1에 python3-colcon-common-extensions 미설치 원인(ROS 2 apt 저장소 미추가) 주석 추가
2026-07-07 feat(bringup): 모터 게인 자동 캘리브 도구 추가
    motor_calib.py 확장(수렴 루프+자동 진단+yaml 기록), scripts/motor_calib_converge.sh, bringup.launch.py(motor_calib.yaml 오버라이드 로드), .gitignore(motor_calib.yaml 무시)
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2026-07-11 chore(git): .gitignore에 .claude/ 추가
    Claude Code 로컬 설정 디렉터리가 저장소에 추적되지 않도록 제외한다.
2026-07-13 docs(readme): 로봇 접속을 IP 대신 호스트명(tribo-robot.local)으로 고정
    DHCP로 로봇 IP가 .14 → .16 → .20 으로 바뀔 때마다 하드코딩된 IP가
    깨지는 문제를 정리한다.
    - 3-4-1 절 추가: ~/.ssh/config 의 Host tribo-robot + mDNS(.local) 방식,
    alias tribo="ssh tribo-robot" 안내
    - 옛 계정/IP 하드코딩 예시 정리 (dtrp@192.168.210.14 → tribo-robot 별칭,
    /home/dtrp/ → /home/tribo/)
    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
2026-07-13 docs(readme): 접속 alias를 tribo로 통일하고 alias 모음 절 추가
    - 존재하지 않는 tribossh 예시 제거 → 실제 사용 중인 tribo로 교체
    - 3-4-2 절 신설: tribo / tribo_ws / kbringup / knav / kall 정리
    - tribo(대화형 접속용) vs tribo-robot(ssh config Host, scp·스크립트용) 역할 구분 명시
    - 3-5 호스트키 절: 기체 교체(v1→v2, hostname 동일) 케이스 포함하도록 수정
    - IP 변경 이력 갱신 (.14 → .16 → .20 → .23)
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2026-07-13 fix(odom): rotation_calib 이 방향 비대칭·명령추종을 보고하도록 수정
    기존 보고는 CW/CCW 를 뭉뚱그려 평균/표준편차만 냈다. 실측(v2)에서
    CW=73.0deg, CCW=82.1deg 로 방향별 계통 비대칭 11.7% 가 있었는데도
    표준편차 0.021 -> '변동 2%, 슬립 안정' 으로 판정하고 두 클러스터의
    중간값(track 0.845)을 권장했다. 그 값은 CW(0.863)/CCW(0.827) 어느
    쪽에도 맞지 않는다.
    또 cmd_vel 대비 실제 회전을 아예 재지 않았다. 개루프 PWM 모드라
    명령 172deg 에 실제 72~78deg(42~45%) 만 도는데도 드러나지 않았다.
    Nav2 회전 undershoot 의 직접 원인이다.
    - 방향(CW/CCW)별 IMU 각·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
2026-07-15 fix(nav): 라이다 self-filter ROI 를 실측 자기구조물 경계로 확장
    요청 사양(전10/후40/좌우30)으로는 자기 몸이 박스 밖으로 삐져나가
    /scan_filtered 에 자기 구조물이 남았다(코스트맵 네 모서리 검은 셀).
    라이다 근접 고정점 스윕으로 실측한 경계 base_link x[-0.11,+0.28] y[±0.32]
    (payload 프레임이 넓어 좌우 0.32, 전방 0.12)에 여유 2cm 를 줘
    max_x 0.26->0.30, min/max_y ±0.30->±0.34 로 확장. 후방(min_x)만 요청
    40cm 유지. 실로봇 검증: 자기구조물(라이다 0.35m 이내) 생존점 0.
2026-07-15 fix(bringup): motor_calib 직진 게인 재정규화 — 게인이 0으로 무한 감소하던 버그
    기존: new_gain[i] = live_gain[i] * (min_rate / abs_rates[i]) 는 계수가 항상
    ≤1 이라 게인이 줄기만 한다. 반복 시 가장 느린 모터의 순위가 바뀌며 네 게인이
    모두 0 으로 ratchet down(관측: max gain 0.73 → 0.619). 재실행할수록 로봇이
    조용히 약해졌다.
    수정: 원계수 계산 후 최대값으로 재정규화(비율 유지, 최대=1.0). 같은 로봇에서
    max gain 0.619 → 1.000 으로 복구 검증. 전부 0 에 가까우면 원값 유지 + 경고.
    [motor_calib.py]
2026-07-15 fix(nav): 라이다 self-filter ROI 확장 (여유 7cm + 후방 40cm)
    이전 여유 2cm 박스는 자기 구조물이 코스트맵 네 모서리에 검은 셀로 남았다.
    사용자 요청으로 전방/좌우를 실측 경계+7cm(x_max 0.30->0.35, y ±0.34->±0.39),
    후방은 min_x -0.24->-0.40(라이다 후방 56cm)로 확대. 로봇에서 실측 검증:
    자기 구조물(라이다 0.35m 이내) 생존점 0, 후방 코너 잔점도 제거.
2026-07-15 refactor: IMU·EKF 완전 제거, 휠 오도메트리 단일 경로로 전환
    이 기체 보드 IMU 는 yaw 를 만들 두 경로가 모두 고장이다: 절대 yaw(orientation)
    는 펌웨어가 갱신 안 하고(freeze), 대안인 자이로(gz)는 지속 회전 약 2.4초(≈24°)
    후 0 으로 죽는다. 라이다 독립 측정(스캔 상관)으로 실제 회전 +133°, 휠 +126°(5%
    일치)인데 IMU 적분만 +24°에서 멈추는 것을 확인. EKF 는 yaw 를 IMU 자이로로만
    추정하므로 회전 중 /odom yaw 가 멈춰 map building 이 깨졌다. 휠·라이다가 일치
    하므로 휠 오도메트리만으로 충분 → IMU·EKF 를 ws 전체에서 제거.
    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
    [gazebo_control.xacro, imu.xacro, robot.urdf.xacro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]
2026-07-16 feat(bringup): 저전압 부저 경고 + 강제 종료, tribolib 종료 race 수정
    - 배터리 v <= buzzer_low_v(10V) 면 buzzer_period_s(2s)마다 짧게 삐빅(보드 BEEP).
    - 저전압이 low_batt_shutdown_s(5s) 연속 지속되면 모터 정지 + 경고음(길게) 후
    bringup 종료(과방전/오작동 방지). 순간 전압 sag 오종료 방지 위해 연속 지속 요구.
    - main 을 spin_once 루프 + _shutting_down 플래그로 바꿔 정상 종료
    (콜백에서 rclpy.shutdown() 직접 호출 시 main finally 와 이중호출되어 에러났음).
    - tribolib: rx_loop 가 close 시 조용히 빠지도록 정지 신호(state=2) + serial
    timeout=0.1 + join 추가. 종료 시 닫힌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
    [bringup.py, bringup.yaml, tribolib.py]
2026-07-18 fix(bringup): wheel_radius 0.040→0.0448 실측 보정 (직진 12% 과소)
    [robot_geom.yaml]
2026-07-18 fix(odom): track_width 0.838→0.950 회전 캘리브 (R 상향 보정 + 6바퀴 검증)
2026-07-20 fix(nav_control): goal_sender yaw 단위 degree 로 통일 (radian 오해석 버그)
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2026-07-21 fix(scripts): find_tribos.sh 의 set -u 제거 (소싱 시 colcon setup 깨짐)
    실행이 아니라 source 로 부르면 nounset 이 대화형 셸에 남아
    이후 `source install/local_setup.bash` 가
    "COLCON_CURRENT_PREFIX: unbound variable" 로 깨졌다.
    스크립트는 이미 모든 외부 변수를 ${VAR:-} 로 개별 방어하고 있어
    set -u 없이도 안전하다. 제거 사유는 주석으로 남긴다.
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2026-07-29 fix(nav): 회전 각가속 3.2→1.5 로 완화해 저전압 컷오프 방지
    회전 급가속이 시작 전류 피크를 키워 배터리 저전압 컷오프를 유발했다.
    RPP/RotationShim(max_angular_accel), behavior_server(rotational_acc_lim),
    velocity_smoother(yaw 축 max_accel/max_decel) 세 곳을 함께 낮춘다.
    한 곳만 낮추면 다른 쪽이 그대로 급가속 명령을 내보내 효과가 없다.
    직진 가속(2.5)은 그대로 둔다 — 전류 피크 원인은 회전 쪽이다.
    회전 시작이 약간 느려지는 것이 트레이드오프. 실로봇 검증 완료.
2026-07-29 fix(nav_control): goal_sender 가 amcl 초기포즈를 원점으로 리셋하던 버그
    BasicNavigator.waitUntilNav2Active() 내부의 _waitForInitialPose() 는
    amcl_pose 를 받을 때까지 self.initial_pose 를 /initialpose 로 발행한다.
    setInitialPose() 를 부른 적이 없으면 그 값이 기본 PoseStamped(), 즉
    맵 원점(0,0,0) 이다. 결과적으로 goal_sender 를 실행할 때마다 RViz 로
    잡아둔 로컬라이제이션이 원점으로 날아갔다(2026-07-20 실측 확인).
    goToPose() 가 내부적으로 같은 서버를 기다리므로 navigate_to_pose 액션
    서버만 기다리면 충분하다. 초기포즈는 건드리지 않는다.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
2026-07-29 fix(geom): 82mm 메카넘 재캘리브 — wheel_radius 0.0430, 물리 track 0.52→0.71
    wheel_radius: 실측 1.7m 주행 대조로 0.0460(시작값) → 0.0430 확정. 재주행 검증에서
    odom 1.8000m 예측에 줄자 1.80m 로 일치. 새 보정계수는 공칭 0.041 대비 ×1.049 로
    고무바퀴 때의 ×1.121 과 달라, 구 0.0448 에는 기체 편차가 섞여 있었다고 본다
    (그 값은 다른 기체 7b6a 에서 라이다 방식으로 측정). 모델 공통값이 아닐 수 있다.
    track_width: 실측 0.71. 기존 0.52 는 오기였다 — bringup.launch.py 주석은 같은 값을
    "physical 0.70 m" 라 적어 리포 내부에서 모순이었다. 바퀴 교체로 바뀐 게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
    [robot_geom.yaml]
2026-07-29 fix(odom): 메카넘 유효 track 0.950 → 1.096
    제자리 2바퀴법: odom 738.1° vs 물리 640° → 0.950 × (738.1/640) = 1.096.
    검증 재측정에서 odom 734.1°(2바퀴+14°) 예측에 물리 2바퀴+10° 로 일치(오차 0.6%,
    눈측정 분해능 ±3% 안쪽).
    ⚠️ 방향이 직관과 반대다. 메카넘은 스크럽 마찰이 줄어 회전이 가벼워지지만, 롤러가
    옆으로 자유롭게 구른다는 건 곧 횡방향 접지력이 없다는 뜻이라 같은 바퀴 이동량에
    로봇은 "덜" 돈다 → 유효 track 은 오히려 커진다. 슬립비 1.34 → 1.54.
    마찰 감소와 접지력 감소는 같이 온다.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
2026-07-29 fix(bringup): PWM 바닥이 저속을 막던 문제 — pwm_min 35→20, max_lin_vel 0.50→0.85
    메카넘은 구름저항이 낮아 pwm_min_percent 35% 바닥이 이미 0.28 m/s 를 냈다. 0이 아닌
    어떤 저속을 명령해도 이 바닥으로 클램프돼, Nav2 가 요구하는 0.2~0.25 는 물리적으로
    추종 불가능했다(명령 0.15에 실제 0.28이 나온 진짜 원인). 20 으로 낮춰 최저속 0.216 m/s.
    max_lin_vel 은 "최고속"이 아니라 정규화 분모다(duty = |v_wheel| / max_lin_vel).
    실측 최고속은 듀티 100%에서 0.443 m/s 로 오히려 0.50 보다 낮지만, 응답이 오목해
    천장값을 그대로 넣으면 분모가 줄어 듀티가 올라가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
    [bringup.yaml]
2026-07-29 fix(nav): 회전·직진 속도 상한을 메카넘 실측값으로 정정
    회전은 명령을 추종하지 않는다 — rotate_pwm_min(35) 바닥이 속도를 결정한다. 명령
    wz 0.4 의 자연 듀티는 16.7% 라 바닥에 클램프되고, 바닥이 안 걸리려면 명령이
    0.84 rad/s 를 넘어야 하는데 Nav2 는 거기까지 안 간다. 즉 이 대역에서 회전은 사실상
    단일 속도 0.367 rad/s(실측)다. 0.5 를 적어두면 컨트롤러가 낼 수 없는 속도로 계획한다.
    - rotate_to_heading_angular_vel 0.5 → 0.37
    - behavior_server max/min_rotational_vel 0.5/0.4 → 0.37/0.35
    - velocity_smoother yaw 상한 0.55 → 0.37 (직진 0.25 는 유지, 실제 0.257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
2026-08-19 fix(geom): 구조 변경 + 100mm 메카넘 실측 재캘리브 (기체 7b6a)
    줄자 실측:
    - 물리 track 0.71 -> 0.74 (좌우 바퀴 중심-중심)
    - 휠베이스 0.40 (신규 기록)
    지상 직진 캘리브로 wheel_radius 0.0430 -> 0.0563:
    - 2.8m 주행, 휠 경로(ticks) vs 실측 경로 비교. 활주 ~5cm 보정.
    - 2.5m 주행(m2 고장 상태)과 2.8m 주행(정비 후)의 ticks/m 이
    12222 vs 12141 로 0.7% 차이뿐이라 두 측정이 서로를 검증한다.
    - 공칭 0.050 대비 x1.125 로, 이 기체가 고무바퀴 시절 쓰던 x1.121 과
    거의 일치한다. 보정계수가 바퀴가 아니라 기체(ticks_per_rev/기어비)에
    붙어 있다는 기존 해석과 맞는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
    [robot_core.xacro, robot_geom.yaml]
2026-08-19 fix(calib): motor_calib 세그먼트 기준점 버그 — 모든 구간 rate 가 누적값이었다
    _cb_enc 가 _enc_prev 를 `if self._enc_prev is None:` 안에서만 채워서
    "노드 기동 후 첫 샘플"에 영구히 고정됐다. _start_segment 는
    _seg_start_enc = _enc_prev 로 잡으므로, 모든 구간의 d_ticks 가
    구간 델타가 아니라 실행 시작부터의 누적이 되고 rate = 누적/구간길이 라는
    무의미한 값이 나왔다.
    증상:
    - stop 구간 rate 가 주행 구간보다 큼 (stop3 가 rotate_left 의 2.5배)
    - backward 가 forward 와 같은 부호
    - rotate_right 의 좌우 부호가 rotate_left 와 동일
    - gain_*_rev_factor 추천값이 실행마다 0.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
    [motor_calib.py]
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2026-08-19 chore(seed): odom 유효 track·gazebo wheel_separation 시드 갱신 (미검증)
    ⚠️ 둘 다 실측이 아니라 시드다. 아직 검증하지 않았다.
    bringup.launch.py 의 odom 유효 track 1.096 -> 1.14
    - 82mm 메카넘 슬립비 1.096/0.71 = 1.544 를 새 물리 track 에 그대로 적용:
    0.74 x 1.544 = 1.143
    - 100mm 롤러는 접지 특성이 다르고 슬립비는 track 보다 휠베이스에 더
    민감하다(구조 변경으로 휠베이스도 바뀜). 제자리 N바퀴 회전 + 출발선
    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
    [gazebo_control.xacro]
2026-08-19 fix(odom): odom 유효 track 실측 확정 1.14 -> 1.1845 (기체 7b6a)
    40d3f11 에서 시드로 넣었던 1.14 를 실측값으로 교체한다.
    측정: scripts/spin_test.py turns 3 (제자리 3바퀴법)
    - odom 누적 1080.6도 vs 물리 실제 1040도(2바퀴 + 320도) -> x1.0390
    - 1.14 x 1.0390 = 1.1845
    ⚠️ 이 방법을 쓰는 이유: odom yaw 자체가 track 으로 계산되므로 odom 을 자로
    쓰면 순환 참조가 된다. 물리 각도만이 독립적인 기준이다. IMU/EKF 를 걷어낸
    뒤로 이 값이 yaw 의 유일한 소스라 정확도가 전적으로 여기 달려 있다.
    슬립비(유효/물리) = 1.1845/0.74 = 1.601.
    76c02a + 82mm 메카넘이 1.096/0.71 =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
2026-08-19 fix(nav): footprint 를 실측 기하로 교체 + 낼 수 없는 최저 접근속도 정정
    robot_radius 0.22 -> 사각 footprint [[0.25,0.39],[0.25,-0.39],[-0.25,-0.39],[-0.25,0.39]]
    - 0.22 는 차체 박스(반폭 0.21)만 본 값이고 좌우로 튀어나온 바퀴가 빠져 있었다.
    - 실측 기하 기준 반폭 0.74/2 + 0.04/2 = 0.39 (전폭 0.78 m),
    반길이 0.40/2 + 0.05 = 0.25 (전장 0.50 m).
    - 즉 실제의 절반짜리 원으로 충돌 검사를 하고 있었다. 바퀴가 벽에 긁힌다.
    - local/global 양쪽에 동일 적용.
    min_approach_linear_velocity 0.05 -> 0.10
    - 0.05 는 물리적으로 낼 수 없다. pwm_min_percent 20 이 만드는 최저 속도가
    0.089 m/s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
2026-08-19 fix(bringup): LCD 해상도를 fb0 대신 xrandr 에서 읽는다
    /sys/class/graphics/fb0/virtual_size 는 프레임버퍼 콘솔 크기이지 X 가 쓰는
    모드가 아니다. 기체 7b6a 에서 fb0 는 1024x768 인데 실제 X 모드는 1024x600 이라
    영상이 화면보다 크게 그려졌다.
    76c02a 에서는 둘이 우연히 같아(1024x600) 문제가 드러나지 않았다. 두 번째 기체에
    올리면서 발견했다. 창 관리자가 창을 잡는 기준은 X 모드이므로 xrandr 을 우선하고,
    실패하면 fb0 로 폴백한다.
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2026-08-20 chore(nav): 참조되지 않는 robot_geom.yaml 삭제
    tribo_navigation/config/robot_geom.yaml 은 어떤 launch 나 코드도 읽지 않는다.
    모든 참조가 tribo_bringup/config/robot_geom.yaml(pkg_bringup)을 가리킨다.
    이력이 8ab5017(패키지 이름 변경) 하나뿐인 잔재로, 82mm·100mm 메카넘 재캘리브를
    한 번도 거치지 않아 값이 낡아 있었다(track 0.40 / radius 0.04 — 실제는 0.74 /
    0.0563). 남겨두면 이 파일을 고치고 "왜 안 바뀌나" 하고 헤매게 된다.
    [robot_geom.yaml]
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2026-08-20 feat(geom): 기체별 odom 기하를 per-unit 오버라이드로 분리
    문제: wheel_radius 와 odom 유효 track 은 기체마다 다른데 저장소는 한 슬롯뿐이다.
    그래서 한 기체 값을 커밋해두고 다른 기체에서는 "미커밋 로컬 수정"으로 덮어쓰고
    있었다. 그 파일을 건드리는 커밋이 하나만 들어와도 pull 때 캘리브가 조용히 날아간다.
    에러도 경고도 없다.
    실측 차이 (둘 다 100mm 메카넘, 물리 track 0.74):
    7b6a4fe0834ff68f : wheel_radius 0.0563, odom track 1.1845
    76c02a59a49ae5ec : wheel_radius 0.0521, odom track 1.1037
    섞이면 10m 주행에 75cm, 360도 회전마다 24도씩 오차가 쌓인다. IMU/EK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
    [robot_geom.yaml]
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2026-08-21 fix(sim): wheel_separation 을 sim 실측 검증값 0.95 로 확정한다
    0.96 은 구 슬립비(0.65/0.50 = 1.30)를 새 물리 트랙 0.74 에 곱한 시드였고
    파일에도 "검증 안 된 시드" 라고 적혀 있었다. 휠베이스가 0.28 -> 0.40 으로
    늘어 sim 의 스크럽 특성이 달라졌으므로 그대로 믿을 수 없었다.
    /odom yaw 와 Gazebo dynamic_pose/info 의 실제 yaw 를 비교해 재측정했다.
    제자리 회전 (+-0.5, 0.3 rad/s 3회) 비율 1.0086 -> 0.952
    주행 중 선회 (v0.2 / w0.37 등) 비율 ~1.015 -> 0.946
    스키드는 두 경우의 슬립이 달라 한 값으로 둘 다 맞출 수 없다. 0.95 는 그
    사이 절충이고 남는 오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
    [gazebo_control.xacro]
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2026-08-21 fix(description): 차체 치수를 바퀴 실측 기하에서 유도한다
    Gazebo 에서 모터가 차체와 떨어져 떠 보였다. 원인은 휠베이스(0.40)가 차체
    전후 길이(0.36)보다 길어 모터 축이 아예 차체 밖에 있었던 것이다. base_y
    0.42 도 "미실측 추정치" 로 표시된 채 구조 변경분이 반영되지 않고 있었다.
    숫자를 베껴 적는 대신 바퀴 실측 기하에서 유도하도록 바꿨다.
    base_x = 2*(wheel_x + wheel_radius) = 0.50
    base_y = 2*(wheel_y - wheel_width/2) = 0.70
    전폭은 바퀴 안쪽 면까지만 잡는다. footprint 전폭 0.78 을 그대로 쓰면 바퀴가
    박스에 파묻히기 때문이다. 이제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
    [robot_core.xacro]
2026-08-31 Add hardware folder: Tribo 3D design files (1차/최종 설계파일, step, stl)
    [035armbase.step-1.step.STEP.step.STEP.ipt, 035armbase.step.step.STEP.step.STEP.iam, 2.0_PIN_HEADER.STEP.STEP.step.STEP.ipt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]
2026-08-31 Add 가공용 도면 folder to hardware
    [AL_Plate_Outer_600X460X2t_DriveTrain.0002.idw, AL_Plate_Outer_600X460X2t_DriveTrain.0003.idw, AL_Plate_Outer_600X460X2t_DriveTrain.dwg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]
